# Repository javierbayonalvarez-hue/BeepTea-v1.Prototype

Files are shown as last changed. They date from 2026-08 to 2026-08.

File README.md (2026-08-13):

🌍 *[Read this in English](README.md) | [Leer en Español](README_ES.md)*

# BeepTEA

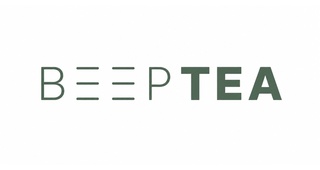
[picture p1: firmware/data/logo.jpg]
BeepTEA Logo


**BeepTEA** is a smartwatch-style smart communicator (based on the LilyGo T-Display-S3 board) specifically designed to help children and individuals with Autism Spectrum Disorder (ASD) or other cognitive needs.

Its main function is to provide visual routines using pictograms and a vibration alert system without relying on a constant internet connection, thereby improving autonomy and reducing anxiety.

---

## 🎯 Main Features
* 📵 **True Independence:** Works 100% offline after initial setup. Keeps time internally via RTC.
* 🖼️ **Visual Routines:** Displays custom pictograms to guide the user through their daily tasks (eating, washing hands, sleeping...).
* 📳 **Friendly Alerts:** The watch vibrates and emits gentle tones when it's time for a new routine, catching attention without causing distress.
* 📶 **On-Demand Connectivity:** The watch hosts its own captive portal (Direct Wi-Fi) for initial setup, and connects via **Bluetooth (BLE)** to sync routines with the mobile App.

## 📦 Project Structure

This repository contains everything needed to build and modify the entire system:

1. `/firmware`: The C++ source code for the ESP32-S3 microcontroller. Ready to be compiled with **PlatformIO**.
2. `/mobile-app`: The source code for the companion mobile application (**BeepTEA Manager**) built with **Capacitor** and vanilla HTML/JS. Allows easy pictogram uploads and routine scheduling via Bluetooth.
3. `/BOM.txt`: Bill of Materials and components used in the project.

## 🛠️ Hardware Requirements

The brain of the project is a **LilyGo T-Display-S3**, a powerful ESP32-S3 with a built-in color IPS display. We added the following to this board:

* **Vibration Motor (Haptic):** Connected to PIN 43.
* **Buzzer:** Connected to PIN 44.
* **Extra Physical Button:** (In addition to the internal buttons on PIN 0 and 14).
* **LiPo Battery:** With smart voltage monitoring (connected to PIN 4).

## 🚀 Installation Guide (Firmware)

1. Install [Visual Studio Code](https://code.visualstudio.com/) and the [PlatformIO](https://platformio.org/) extension.
2. Open the `/firmware` folder in VS Code.
3. Connect your LilyGo T-Display-S3 board via USB.
4. First, compile and upload the filesystem (LittleFS) using the **`Upload File System Image`** option in PlatformIO (this uploads the captive portal and the logo).
5. Second, compile and upload the source code using the **`Upload`** option.

## 📱 Build Guide (Mobile App)

To compile the mobile app, you will need [Node.js](https://nodejs.org/) and Android Studio.

1. Open the `/mobile-app` folder in your terminal.
2. Install dependencies: `npm install`
3. Sync the web code with the native Android project: `npx cap sync android`
4. Open it in Android Studio to build your APK: `npx cap open android`

## 🤝 Credits and Collaboration

A project created with dedication to make life easier and foster autonomy for people with ASD. Feel free to fork, improve, or propose new features by opening a *Pull Request*!

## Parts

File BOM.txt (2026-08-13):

BUSCATEA DIGITAL - BOM / LISTA DE COMPRA
Version: MVP hardware
Fecha: 2026-05-05

OBJETIVO
Dispositivo tipo busca/pager para rutinas visuales con pictogramas, vibracion, sonido, RTC y botones fisicos.

1. ELECTRONICA PRINCIPAL

[ ] 1x LILYGO T-Display-S3 ESP32-S3
    - Pantalla 1.9" ST7789, 170 x 320.
    - 16 MB Flash, 8 MB PSRAM.
    - Conector bateria JST-GH 1.25 mm 2P.
    - Mejor version sin touch para evitar distracciones.

[ ] 1x Bateria LiPo 3.7 V 1200 mAh modelo 103450
    - Preferible con circuito de proteccion integrado.
    - Conector compatible JST-GH 1.25 mm 2P o adaptador.

[ ] 1x Modulo RTC DS3231 Mini I2C
    - Alimentacion a 3.3 V.
    - Conexiones: VCC, GND, SDA, SCL.
    - Revisar si trae circuito de carga para pila LIR2032 antes de usar CR2032/CR1220.

[ ] 1x Pila para RTC
    - CR1220, CR2032 o LIR2032 segun el modulo DS3231 comprado.
    - No usar pila no recargable si el modulo intenta cargarla.

2. FEEDBACK / ALERTAS

[ ] 1x Modulo motor de vibracion tipo moneda con driver integrado
    - Pines: IN, VCC, GND.
    - Conexion recomendada:
      IN  -> GPIO 1
      VCC -> 3V3
      GND -> GND
    - Al usar este modulo NO hace falta comprar MOSFET, diodo ni resistencias para el motor.

[ ] 1x Buzzer pasivo 3 V / piezo pasivo
    - Conexion MVP:
      positivo -> GPIO 2
      negativo -> GND
    - Si el buzzer elegido consume mucho, anadir transistor/MOSFET como driver.

3. ENTRADA FISICA

[ ] 0x Pulsadores externos para el MVP de pruebas
    - De momento se usan los 2 botones integrados de la LILYGO T-Display-S3.
    - Boton integrado GPIO 0 -> OK / confirmar.
    - Boton integrado GPIO 14 -> Menu / Necesidades.
    - No hace falta comprar botones externos para probar firmware y app.

4. CARCASA Y MONTAJE

[ ] 1x Carcasa impresa en PETG
    - Formato tipo busca/pager.
    - Huecos para pantalla, USB-C, botones y sonido.
    - Espacio para bateria 103450 y cableado.

[ ] 1x Clip metalico de cinturon
    - Preferible metalico por resistencia.

[ ] 1 lote tornillos M2 / M2.5
    - Segun diseno de carcasa.

[ ] 1 lote insertos termicos M2 / M2.5
    - Recomendado si la carcasa se abre/cierra muchas veces.

[ ] 1 pieza espuma EVA fina o almohadilla adhesiva
    - Para sujetar bateria y evitar vibraciones internas.

5. HERRAMIENTAS / CONSUMIBLES

[ ] Cable USB-A a USB-C de datos
    - Para programar el LILYGO.
    - LILYGO recomienda cable USB 2.0 A-C.

[ ] Estaño fino para electronica

[ ] Flux

[ ] Cinta Kapton o aislante fino

[ ] Multimetro
    - Para comprobar continuidad, polaridad de bateria y modulo DS3231.

6. COMPONENTES QUE YA NO SON NECESARIOS SI USAS EL MODULO DE VIBRACION DE LA FOTO

[ ] MOSFET canal N para motor
[ ] Resistencia gate 100 ohm para motor
[ ] Resistencia pulldown 100k para motor
[ ] Diodo flyback para motor

Nota: mantenerlos solo si se decide usar un motor suelto sin placa driver.

7. PINOUT MVP

Motor vibracion modulo:
IN  -> GPIO 1
VCC -> 3V3
GND -> GND

Buzzer pasivo:
+ -> GPIO 2
- -> GND

Boton OK:
GPIO 0 -> boton integrado LILYGO

Boton Menu:
GPIO 14 -> boton integrado LILYGO

RTC DS3231:
VCC -> 3V3
GND -> GND
SDA -> GPIO 17
SCL -> GPIO 18

Bateria:
LiPo 3.7 V -> JST-GH 1.25 mm 2P del LILYGO

8. NOTAS DE SEGURIDAD

- No alimentar el DS3231 a 5 V.
- No usar CR2032/CR1220 si el modulo DS3231 intenta cargar la pila.
- No conectar motor suelto directamente a GPIO. El modulo de vibracion con driver si puede ir por IN.
- Todos los GND deben estar unidos.
- Proteger fisicamente la bateria dentro de la carcasa.
- Evitar piezas pequenas sueltas en un dispositivo infantil.

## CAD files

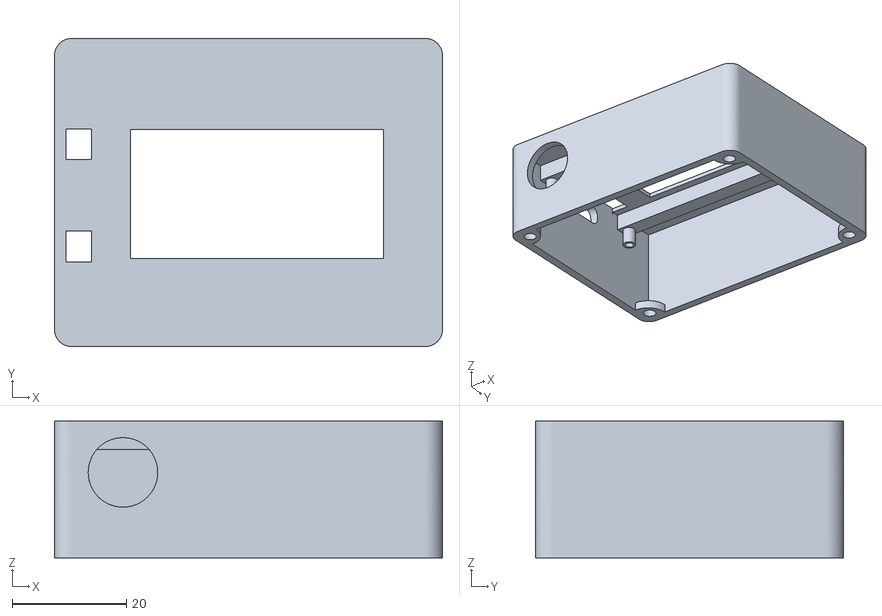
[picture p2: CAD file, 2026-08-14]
3D Models/BeepTeaTop.stl
68.0 x 54.0 x 24.0

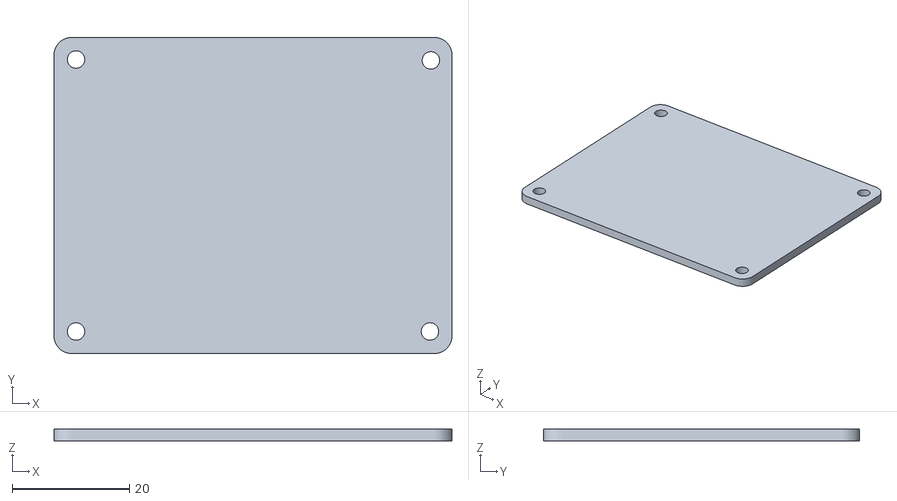
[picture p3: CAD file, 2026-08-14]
3D Models/BeepTeaBack.stl
68.0 x 54.0 x 2.00

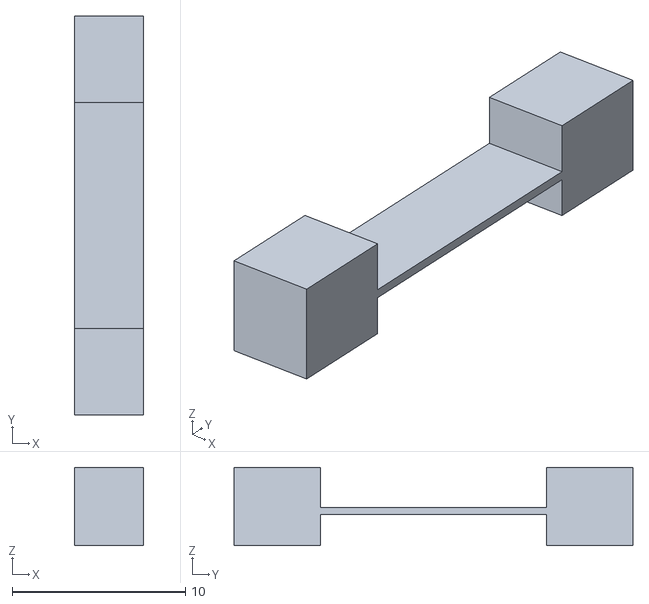
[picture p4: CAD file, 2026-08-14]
3D Models/BeepTEAButtons.stl
4.00 x 23.0 x 4.50

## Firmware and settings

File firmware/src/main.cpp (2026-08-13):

#include <Arduino.h>
#include <ArduinoJson.h>
#include <ESPAsyncWebServer.h>
#include <ESPmDNS.h>
#include <LittleFS.h>
#include <NimBLEDevice.h>
#include <Preferences.h>
#include <RTClib.h>
#include <TFT_eSPI.h>
#include <TJpg_Decoder.h>
#include <WiFi.h>
#include <Wire.h>
#include <time.h>
#include <driver/gpio.h>

#include "config.h"

struct RoutineItem {
  String id;
  String title;
  uint16_t startMin;
  uint16_t endMin;
  bool completed;
};

static TFT_eSPI tft;
static RTC_DS3231 rtc;
static AsyncWebServer server(80);
static Preferences prefs;
static NimBLECharacteristic *bleStatus = nullptr;

static bool bleConnected = false;
static RoutineItem routine[24];
static size_t routineCount = 0;
static int activeIndex = -1;
static bool rtcAvailable = false;
static bool wifiConnected = false;
static bool setupMode = false;
static bool restartPending = false;
static wl_status_t lastWifiStatus = WL_IDLE_STATUS;
static String attemptedWifiSsid = "";
static bool needsMenuOpen = false;
static bool alertRunning = false;
static uint32_t alertStartedAt = 0;
static bool deviceVibration = true;
static bool deviceSound = true;
static uint8_t routineDaysMask = 0xFF;
static uint32_t deviceAlertMs = 3000;

RTC_DATA_ATTR uint8_t brightnessLevel = 1; // 0=Bajo, 1=Medio, 2=Alto

static void applyBrightness() {
  if (brightnessLevel == 0) ledcWrite(2, 50); // 20%
  else if (brightnessLevel == 1) ledcWrite(2, 140); // 55%
  else ledcWrite(2, 255); // 100%
}

static uint32_t lastDrawAt = 0;
static uint32_t okPressedAt = 0;
static uint32_t menuPressedAt = 0;
static bool okWasDown = false;
static bool menuWasDown = false;
static uint32_t restartAt = 0;

static uint32_t lastInteractionTime = 0;
static bool screenIsAsleep = false;

static void applyNetworkMode();
static void disableNetwork();

static bool previewMode = false;
static uint32_t previewStartedAt = 0;
static int previewIndex = -1;

static String routineName = "Sin rutina";
static String childName = "BuscaTEA";
static bool infoMode = false;
static uint32_t infoStartedAt = 0;
static bool menuLongPressed = false;
static int networkMode = 0;
static int lastDrawnIndex = -2;
static bool lastDrawnNeedsMenu = false;
static uint16_t lastDrawnMinute = 9999;
static bool lastDrawnCompleted = false;
static uint8_t lastDrawnProgress = 255;
static String lastDrawnIp = "";
static int lastDrawnBattery = -1;

static bool tftJpegOutput(int16_t x, int16_t y, uint16_t w, uint16_t h, uint16_t *bitmap) {
  if (y >= SCREEN_H) return false;
  tft.pushImage(x, y, w, h, bitmap);
  return true;
}

static uint16_t parseTimeToMinutes(const String &value) {
  int sep = value.indexOf(':');
  if (sep < 0) return 0;
  int hh = value.substring(0, sep).toInt();
  int mm = value.substring(sep + 1).toInt();
  hh = constrain(hh, 0, 23);
  mm = constrain(mm, 0, 59);
  return hh * 60 + mm;
}

static String minutesToTime(uint16_t value) {
  char buffer[6];
  snprintf(buffer, sizeof(buffer), "%02u:%02u", value / 60, value % 60);
  return String(buffer);
}

static float batteryMultiplier = 2.00f;

static uint32_t readBatteryMilliVolts() {
  analogRead(PIN_BATTERY_ADC); // dummy
  uint32_t sum = 0;
  for (int i = 0; i < 16; i++) {
    sum += analogReadMilliVolts(PIN_BATTERY_ADC);
    delay(1);
  }
  uint32_t raw_mv = (sum / 16) * 2;
  // Calibración por hardware: El LED de carga marca 100% (4200mV físicos), 
  // pero el ADC lee ~3952mV debido a la tolerancia de las resistencias. 
  // Factor de corrección: 4200 / 3952 = 1.0627
  return (uint32_t)(raw_mv * 1.0627f);
}

static int batteryPercent() {
  uint32_t millivolts = readBatteryMilliVolts();
  
  struct VoltageMap {
    uint32_t mv;
    int percentage;
  };
  
  static const VoltageMap table[] = {
    {4200, 100},
    {4100, 95},
    {4000, 85},
    {3900, 75},
    {3800, 60},
    {3700, 40},
    {3600, 15},
    {3500, 5},
    {3400, 0}
  };
  
  if (millivolts >= table[0].mv) return 100;
  if (millivolts <= table[8].mv) return 0;
  
  for (int i = 0; i < 8; i++) {
    if (millivolts <= table[i].mv && millivolts >= table[i+1].mv) {
      float frac = (float)(table[i].mv - millivolts) / (table[i].mv - table[i+1].mv);
      return table[i].percentage - frac * (table[i].percentage - table[i+1].percentage);
    }
  }
  return 0;
}

static void tftSleep() {
  ledcWrite(2, 0);
  ledcDetachPin(PIN_LCD_BACKLIGHT);
  pinMode(PIN_LCD_BACKLIGHT, OUTPUT);
  digitalWrite(PIN_LCD_BACKLIGHT, LOW);
  tft.writecommand(0x10); // ST7789_SLPIN
  
  pinMode(TFT_CS, INPUT);
  pinMode(TFT_DC, INPUT);
  pinMode(TFT_RST, INPUT);
  pinMode(TFT_WR, INPUT);
  pinMode(TFT_RD, INPUT);
  pinMode(TFT_D0, INPUT);
  pinMode(TFT_D1, INPUT);
  pinMode(TFT_D2, INPUT);
  pinMode(TFT_D3, INPUT);
  pinMode(TFT_D4, INPUT);
  pinMode(TFT_D5, INPUT);
  pinMode(TFT_D6, INPUT);
  pinMode(TFT_D7, INPUT);
  
  digitalWrite(PIN_POWER_ON, LOW);
  gpio_hold_en((gpio_num_t)PIN_POWER_ON); // Bloqueo hermético del pin en sleep
}

class TFT_eSPI_Hack : public TFT_eSPI {
public:
  void forceBooted() { _booted = true; }
};

static void tftWake() {
  gpio_hold_dis((gpio_num_t)PIN_POWER_ON);
  digitalWrite(PIN_POWER_ON, HIGH);
  delay(120); 
  
  ((TFT_eSPI_Hack*)&tft)->forceBooted();
  tft.init();
  tft.writecommand(0x11); // SLPOUT
  delay(120);
  
  ledcSetup(2, 10000, 8);
  ledcAttachPin(PIN_LCD_BACKLIGHT, 2);
  applyBrightness();
}

static String activeIp() {
  if (wifiConnected) return WiFi.localIP().toString();
  if (setupMode) return WiFi.softAPIP().toString();
  return "0.0.0.0";
}

static String wifiModeName() {
  if (wifiConnected) return "station";
  if (setupMode) return "setup";
  return "offline";
}

static String wifiStatusName(wl_status_t status) {
  switch (status) {
    case WL_IDLE_STATUS: return "IDLE";
    case WL_NO_SSID_AVAIL: return "NO_SSID";
    case WL_SCAN_COMPLETED: return "SCAN_DONE";
    case WL_CONNECTED: return "CONNECTED";
    case WL_CONNECT_FAILED: return "CONNECT_FAILED";
    case WL_CONNECTION_LOST: return "CONNECTION_LOST";
    case WL_DISCONNECTED: return "DISCONNECTED";
    default: return String(static_cast<int>(status));
  }
}

static void updateBleStatus();
static void drawScreen(bool force = false);

static uint16_t currentMinuteOfDay() {
  if (rtcAvailable) {
    DateTime now = rtc.now();
    return now.hour() * 60 + now.minute();
  }

  uint32_t seconds = millis() / 1000;
  return (seconds / 60) % 1440;
}

static uint16_t currentToneFreq = 0;
static void safeTone(uint16_t freq) {
  if (currentToneFreq != freq) {
    currentToneFreq = freq;
    ledcWriteTone(0, freq);
  }
}

static void buzz(uint16_t freq, uint16_t durationMs) {
  safeTone(freq);
  delay(durationMs);
  safeTone(0);
}

static void startTransitionAlert() {
  if (screenIsAsleep) {
    screenIsAsleep = false;
    tftWake();
    tft.setRotation(1);
    drawScreen(true);
  }

  alertRunning = true;
  alertStartedAt = millis();
  lastInteractionTime = millis();
  if (deviceVibration) {
    digitalWrite(PIN_VIBRATION, HIGH);
  }
  if (deviceSound) {
  }
}

static void updateAlert() {
  if (!alertRunning) return;
  uint32_t elapsed = millis() - alertStartedAt;
  
    if (elapsed >= deviceAlertMs) {
    digitalWrite(PIN_VIBRATION, LOW);
    if (deviceSound) safeTone(0);
    alertRunning = false;
    return;
  }
  
  if (deviceSound) {
    uint32_t t = elapsed % 1600;
    if (t < 600) {
      uint32_t cycle = t % 150;
      if (cycle < 100) safeTone(4000);
      else safeTone(0);
    } else {
      safeTone(0);
    }
  }
}

static bool loadRoutine() {
  routineCount = 0;
  routineName = "Sin rutina";
  File file = LittleFS.open(ROUTINE_PATH, "r");
  if (!file) return false;

  JsonDocument doc;
  DeserializationError err = deserializeJson(doc, file);
  file.close();
  if (err) return false;

  routineName = doc["name"] | "Sin rutina";
  childName = doc["child"] | "BuscaTEA";
  deviceVibration = doc["vibration"] | true;
  deviceSound = doc["sound"] | true;
  routineDaysMask = 0;
  JsonArray dArr = doc["days"].as<JsonArray>();
  if (dArr.isNull() || dArr.size() == 0) {
    routineDaysMask = 0xFF;
  } else {
    for (JsonVariant v : dArr) {
      routineDaysMask |= (1 << v.as<int>());
    }
  }
  int durationSec = doc["alertDuration"] | 3;
  deviceAlertMs = durationSec * 1000;

  JsonArray items = doc["items"].as<JsonArray>();
  for (JsonObject item : items) {
    if (routineCount >= 24) break;
    routine[routineCount].id = item["id"] | "";
    routine[routineCount].title = item["title"] | routine[routineCount].id;
    routine[routineCount].startMin = parseTimeToMinutes(item["start"] | "00:00");
    routine[routineCount].endMin = parseTimeToMinutes(item["end"] | "00:00");
    routine[routineCount].completed = false;
    routineCount++;
  }
  return routineCount > 0;
}

static int findActiveRoutineIndex(uint16_t minute) {
  if (rtcAvailable) {
    DateTime now = rtc.now();
    int dayW = now.dayOfTheWeek();
    int mappedDay = (dayW == 0) ? 7 : dayW;
    if (!(routineDaysMask & (1 << mappedDay))) {
      return -1;
    }
  }
  for (size_t i = 0; i < routineCount; i++) {

    if (routine[i].startMin <= routine[i].endMin) {
      if (minute >= routine[i].startMin && minute < routine[i].endMin) return i;
    } else {
      if (minute >= routine[i].startMin || minute < routine[i].endMin) return i;
    }
  }
  return -1;
}

static uint8_t progressFor(const RoutineItem &item, uint16_t minute) {
  int start = item.startMin;
  int end = item.endMin;
  int now = minute;

  if (end <= start) end += 1440;
  if (now < start) now += 1440;

  int total = max(1, end - start);
  int elapsed = constrain(now - start, 0, total);
  return (elapsed * 100) / total;
}

static void drawBatteryIcon(int x, int y, int w, int h, int percent, bool charging) {
  uint16_t color = tft.color565(16, 185, 129);
  if (charging) {
    color = TFT_YELLOW;
  } else if (percent < 20) {
    color = tft.color565(239, 68, 68);
  } else if (percent < 50) {
    color = tft.color565(249, 115, 22);
  }
  
  tft.drawRect(x, y, w - 2, h, color);
  tft.fillRect(x + w - 2, y + 2, 2, h - 4, color);
  
  if (charging) {
    tft.fillRect(x + 2, y + 2, w - 6, h - 4, color);
    tft.drawLine(x + w/2 - 2, y + 2, x + w/2, y + h/2, TFT_BLACK);
    tft.drawLine(x + w/2, y + h/2, x + w/2 - 2, y + h/2, TFT_BLACK);
    tft.drawLine(x + w/2 - 2, y + h/2, x + w/2 + 2, y + h - 2, TFT_BLACK);
  } else {
    int fillW = ((w - 4) * percent) / 100;
    if (fillW > 0) {
      tft.fillRect(x + 2, y + 2, fillW, h - 4, color);
    }
  }
}

static void drawWifiIcon(int x, int y, int rssi, bool apMode, bool connected) {
  if (!connected) {
    if (apMode) {
      tft.setTextDatum(ML_DATUM);
      tft.setTextColor(tft.color565(249, 115, 22), tft.color565(15, 23, 42));
      tft.drawString("AP", x, y + 4, 1);
    } else {
      uint16_t gray = tft.color565(80, 80, 90);
      tft.fillRect(x, y + 6, 2, 2, gray);
      tft.fillRect(x + 4, y + 4, 2, 4, gray);
      tft.fillRect(x + 8, y + 2, 2, 6, gray);
      tft.fillRect(x + 12, y, 2, 8, gray);
      tft.drawLine(x - 2, y, x + 14, y + 8, tft.color565(239, 68, 68));
    }
  } else {
    int bars = 1;
    if (rssi >= -55) bars = 4;
    else if (rssi >= -70) bars = 3;
    else if (rssi >= -85) bars = 2;
    
    uint16_t barColor = tft.color565(16, 185, 129);
    uint16_t inactiveColor = tft.color565(50, 50, 60);
    
    tft.fillRect(x, y + 6, 2, 2, (bars >= 1) ? barColor : inactiveColor);
    tft.fillRect(x + 4, y + 4, 2, 4, (bars >= 2) ? barColor : inactiveColor);
    tft.fillRect(x + 8, y + 2, 2, 6, (bars >= 3) ? barColor : inactiveColor);
    tft.fillRect(x + 12, y, 2, 8, (bars >= 4) ? barColor : inactiveColor);
  }
}

static void drawBleIcon(int x, int y, bool connected) {
  uint16_t color = connected ? tft.color565(59, 130, 246) : tft.color565(80, 80, 90);
  tft.drawLine(x + 3, y, x + 3, y + 8, color);
  tft.drawLine(x + 3, y, x + 6, y + 2, color);
  tft.drawLine(x + 6, y + 2, x + 3, y + 4, color);
  tft.drawLine(x + 3, y + 4, x + 6, y + 6, color);
  tft.drawLine(x + 6, y + 6, x + 3, y + 8, color);
  tft.drawLine(x + 3, y + 2, x, y, color);
  tft.drawLine(x + 3, y + 6, x, y + 8, color);
}

static void drawSoundIcon(int x, int y, bool enabled) {
  uint16_t color = enabled ? tft.color565(186, 195, 210) : tft.color565(80, 80, 90);
  tft.fillRect(x, y + 2, 3, 4, color);
  tft.drawLine(x + 3, y + 2, x + 6, y, color);
  tft.drawLine(x + 3, y + 5, x + 6, y + 7, color);
  tft.fillRect(x + 6, y, 1, 8, color);
  if (enabled) {
    tft.drawPixel(x + 8, y + 2, color);
    tft.drawPixel(x + 9, y + 3, color);
    tft.drawPixel(x + 9, y + 4, color);
    tft.drawPixel(x + 8, y + 5, color);
  }
}

static void drawVibrationIcon(int x, int y, bool enabled) {
  uint16_t color = enabled ? tft.color565(186, 195, 210) : tft.color565(80, 80, 90);
  tft.drawRect(x + 2, y + 1, 6, 8, color);
  if (enabled) {
    tft.drawPixel(x, y + 2, color);
    tft.drawPixel(x + 1, y + 3, color);
    tft.drawPixel(x + 1, y + 5, color);
    tft.drawPixel(x, y + 6, color);
    tft.drawPixel(x + 9, y + 2, color);
    tft.drawPixel(x + 8, y + 3, color);
    tft.drawPixel(x + 8, y + 5, color);
    tft.drawPixel(x + 9, y + 6, color);
  }
}

static void drawRoundRectGradientH(int x, int y, int w, int h, int r, uint16_t colorStart, uint16_t colorEnd) {
  uint8_t rS = (colorStart >> 11) & 0x1F;
  uint8_t gS = (colorStart >> 5) & 0x3F;
  uint8_t bS = colorStart & 0x1F;
  
  uint8_t rE = (colorEnd >> 11) & 0x1F;
  uint8_t gE = (colorEnd >> 5) & 0x3F;
  uint8_t bE = colorEnd & 0x1F;
  
  for (int i = 0; i < w; i++) {
    float t = (float)i / (w - 1);
    uint8_t rC = rS + t * (rE - rS);
    uint8_t gC = gS + t * (gE - gS);
    uint8_t bC = bS + t * (bE - bS);
    uint16_t color = (rC << 11) | (gC << 5) | bC;
    
    int dy = 0;
    if (i < r) {
      int dx = r - i;
      dy = sqrt(r * r - dx * dx);
      tft.drawFastVLine(x + i, y + r - dy, 2 * dy + (h - 2 * r), color);
    } else if (i >= w - r) {
      int dx = i - (w - r);
      dy = sqrt(r * r - dx * dx);
      tft.drawFastVLine(x + i, y + r - dy, 2 * dy + (h - 2 * r), color);
    } else {
      tft.drawFastVLine(x + i, y, h, color);
    }
  }
}
static bool isCharging() {
  static uint32_t lastCheckMillis = 0;
  static uint32_t lastVolts = 0;
  static bool chargingState = false;
  
  uint32_t currentVolts = readBatteryMilliVolts();
  uint32_t now = millis();
  
  // Inicialización en el primer arranque
  if (lastVolts == 0) {
    lastVolts = currentVolts;
    lastCheckMillis = now;
    // Si al arrancar el voltaje es inusualmente alto (por encima del 100% natural), asumimos que está enchufado
    if (currentVolts > 4250) chargingState = true; 
    return chargingState;
  }
  
  // Revisamos la tendencia cada 2 segundos
  if (now - lastCheckMillis > 2000) {
    int32_t delta = (int32_t)currentVolts - (int32_t)lastVolts;
    
    // Idea 1: Salto brusco hacia arriba (>50mV en 2 seg) = Acaban de enchufar el cable
    if (delta > 50) {
      chargingState = true;
    } 
    // Bajón brusco rápido (>-50mV) = Acaban de quitar el cable
    else if (delta < -50) {
      chargingState = false;
    }
    
    // Seguridad: Si el voltaje es mecánicamente superior al tope natural de la batería, está enchufado
    if (currentVolts > 4250) {
      chargingState = true;
    }
    
    // Idea 2: Si hay conexión de datos USB por puerto serie con un PC, sabemos seguro que está enchufado
    if (Serial) {
      chargingState = true;
    }
    
    lastVolts = currentVolts;
    lastCheckMillis = now;
  }
  
  return chargingState;
}

static void drawHeader(uint16_t minute) {
  tft.fillRect(0, 0, SCREEN_W, 22, tft.color565(15, 23, 42));
  tft.drawFastHLine(0, 22, SCREEN_W, tft.color565(51, 65, 85));

  tft.setTextDatum(ML_DATUM);
  tft.setTextColor(TFT_WHITE, tft.color565(15, 23, 42));
  tft.drawString(minutesToTime(minute), 10, 11, 2);

  tft.setTextDatum(MC_DATUM);
  tft.setTextColor(tft.color565(148, 163, 184), tft.color565(15, 23, 42));
  tft.drawString(childName, 95, 11, 2);

  int bat = batteryPercent();
  bool charging = isCharging();
  
  tft.setTextDatum(MR_DATUM);
  if (charging) {
    tft.setTextColor(TFT_YELLOW, tft.color565(15, 23, 42));
    tft.drawString("CHG", 292, 11, 2);
  } else {
    tft.setTextColor(TFT_WHITE, tft.color565(15, 23, 42));
    tft.drawString(String(bat), 292, 11, 2);
  }

  drawBatteryIcon(296, 4, 20, 10, bat, charging);
  int rssi = wifiConnected ? WiFi.RSSI() : -100;
  drawWifiIcon(250, 7, rssi, setupMode, wifiConnected);
  drawBleIcon(230, 7, bleConnected);
  drawVibrationIcon(210, 7, deviceVibration);
  drawSoundIcon(190, 7, deviceSound);
}

static void drawBorderProgress(int x, int y, int w, int h, int thickness, uint8_t progress, uint16_t activeColor, uint16_t inactiveColor) {
  for (int t = 0; t < thickness; t++) {
    tft.drawRect(x - t, y - t, w + 2 * t, h + 2 * t, inactiveColor);
  }

  int topProgress = constrain(progress, 0, 25);
  for (int t = 0; t < thickness; t++) {
    int topW = (topProgress * (w + 2 * t)) / 25;
    tft.drawFastHLine(x - t, y - t, topW, activeColor);
  }

  if (progress > 25) {
    int rightProgress = constrain(progress - 25, 0, 25);
    for (int t = 0; t < thickness; t++) {
      int rightH = (rightProgress * (h + 2 * t)) / 25;
      tft.drawFastVLine(x + w - 1 + t, y - t, rightH, activeColor);
    }
  }

  if (progress > 50) {
    int bottomProgress = constrain(progress - 50, 0, 25);
    for (int t = 0; t < thickness; t++) {
      int bottomW = (bottomProgress * (w + 2 * t)) / 25;
      tft.drawFastHLine(x + w - 1 + t - bottomW, y + h - 1 + t, bottomW, activeColor);
    }
  }

  if (progress > 75) {
    int leftProgress = constrain(progress - 75, 0, 25);
    for (int t = 0; t < thickness; t++) {
      int leftH = (leftProgress * (h + 2 * t)) / 25;
      tft.drawFastVLine(x - t, y + h - 1 + t - leftH, leftH, activeColor);
    }
  }
}

static int findNextRoutineIndex(uint16_t minute) {
  if (routineCount == 0) return -1;
  if (rtcAvailable) {
    DateTime now = rtc.now();
    int dayW = now.dayOfTheWeek();
    int mappedDay = (dayW == 0) ? 7 : dayW;
    if (!(routineDaysMask & (1 << mappedDay))) return -1;
  }
  if (activeIndex >= 0 && (size_t)(activeIndex + 1) < routineCount) {
    return activeIndex + 1;
  }
  for (size_t i = 0; i < routineCount; i++) {
    if (routine[i].startMin > minute) {
      return i;
    }
  }
  return 0;
}

static bool drawPictogramImage(const RoutineItem &item, int picX, int picY, int picW, int picH) {
  String jpgPath = "/pictos/" + item.id + ".jpg";
  String jpegPath = "/pictos/" + item.id + ".jpeg";
  String path = LittleFS.exists(jpgPath) ? jpgPath : jpegPath;
  if (!LittleFS.exists(path)) return false;

  tft.fillRect(picX, picY, picW, picH, TFT_WHITE);

  uint16_t jpgW = 0;
  uint16_t jpgH = 0;
  TJpgDec.getFsJpgSize(&jpgW, &jpgH, path, LittleFS);
  uint8_t scale = 1;
  while ((jpgW / scale > (picW - 6) || jpgH / scale > (picH - 6)) && scale < 8) {
    scale *= 2;
  }
  TJpgDec.setJpgScale(scale);

  int16_t drawW = jpgW / scale;
  int16_t drawH = jpgH / scale;
  int16_t x = picX + max(0, (picW - drawW) / 2);
  int16_t y = picY + max(0, (picH - drawH) / 2);
  TJpgDec.drawFsJpg(x, y, path, LittleFS);
  return true;
}

static void drawPictogramPlaceholder(const RoutineItem &item, int picX, int picY, int picW, int picH) {
  tft.fillRect(picX, picY, picW, picH, TFT_WHITE);
  tft.setTextDatum(MC_DATUM);
  tft.setTextColor(TFT_BLACK, TFT_WHITE);
  tft.drawString(item.id.substring(0, 10), picX + picW / 2, picY + picH / 2, 2);
}
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
void loop() {
  handleButtons();
  updateAlert();
  
  if (!screenIsAsleep) {
    drawScreen();
    
    if (!previewMode && !infoMode) {
      uint32_t timeoutMs = (activeIndex >= 0) ? 180000 : 60000;
      if (millis() - lastInteractionTime > timeoutMs) {
        screenIsAsleep = true;
        tftSleep();
      }
    }
  } else {
    Serial.flush();
    Serial.end();
    
    gpio_wakeup_enable((gpio_num_t)PIN_BUTTON_OK, GPIO_INTR_LOW_LEVEL);
    gpio_wakeup_enable((gpio_num_t)PIN_BUTTON_MENU, GPIO_INTR_LOW_LEVEL);
    esp_sleep_enable_gpio_wakeup();
    
    esp_sleep_enable_timer_wakeup(60000000ULL);
    
    esp_err_t err = esp_light_sleep_start();
    if (err != ESP_OK) {
      Serial.begin(115200);
      Serial.printf("Light sleep failed! err: %d\n", err);
      delay(1000);
    } else {
      Serial.begin(115200);
    }
    
    esp_sleep_wakeup_cause_t cause = esp_sleep_get_wakeup_cause();
    if (cause == ESP_SLEEP_WAKEUP_TIMER) {
      uint16_t minute = currentMinuteOfDay();
      
      static uint16_t lastMinuteSleep = 9999;
      if (lastMinuteSleep != 9999 && minute < lastMinuteSleep) {
        for (size_t i = 0; i < routineCount; i++) routine[i].completed = false;
      }
      lastMinuteSleep = minute;

      int nextActive = findActiveRoutineIndex(minute);
      if (nextActive != activeIndex) {
        screenIsAsleep = false;
        tftWake();
        tft.setRotation(1);
        lastInteractionTime = millis();
        drawScreen(true);
      }
    } else if (cause == ESP_SLEEP_WAKEUP_GPIO || cause == ESP_SLEEP_WAKEUP_EXT1) {
      screenIsAsleep = false;
      tftWake();
      tft.setRotation(1);
      okWasDown = true;
      menuWasDown = true;
      lastInteractionTime = millis();
      drawScreen(true);
    }
  }
  if (restartPending && millis() >= restartAt) {
    ESP.restart();
  }
  static uint32_t lastBleUpdate = 0;
  if (millis() - lastBleUpdate > 5000) {
    lastBleUpdate = millis();
    updateBleStatus();
  }
}

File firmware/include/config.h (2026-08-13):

#pragma once

#include <Arduino.h>

#if defined(ARDUINO_SEEED_XIAO_ESP32S3)
static constexpr uint16_t SCREEN_W = 320;
static constexpr uint16_t SCREEN_H = 240;

static constexpr uint8_t PIN_VIBRATION = 43;      // D6
static constexpr uint8_t PIN_BUZZER = 44;         // D7
static constexpr uint8_t PIN_BUTTON_OK = 1;       // D0
static constexpr uint8_t PIN_BUTTON_MENU = 2;     // D1
static constexpr uint8_t PIN_POWER_ON = 15;       // Unused GPIO on XIAO (acting as dummy)
static constexpr uint8_t PIN_BATTERY_ADC = 4;     // D3 / A3
static constexpr uint8_t PIN_LCD_BACKLIGHT = 8;   // D9

static constexpr uint8_t PIN_I2C_SDA = 5;         // D4
static constexpr uint8_t PIN_I2C_SCL = 6;         // D5
#else
static constexpr uint16_t SCREEN_W = 320;
static constexpr uint16_t SCREEN_H = 170;

static constexpr uint8_t PIN_VIBRATION = 1;
static constexpr uint8_t PIN_BUZZER = 2;
static constexpr uint8_t PIN_BUTTON_OK = 0;
static constexpr uint8_t PIN_BUTTON_MENU = 14;
static constexpr uint8_t PIN_POWER_ON = 15;
static constexpr uint8_t PIN_BATTERY_ADC = 4;
static constexpr uint8_t PIN_LCD_BACKLIGHT = 38;

static constexpr uint8_t PIN_I2C_SDA = 17;
static constexpr uint8_t PIN_I2C_SCL = 18;
#endif


static constexpr uint32_t LONG_PRESS_MS = 900;
static constexpr uint32_t DISPLAY_REFRESH_MS = 1000;
static constexpr uint32_t ALERT_PATTERN_MS = 1400;

static constexpr const char *ROUTINE_PATH = "/rutina.json";
static constexpr const char *DEVICE_NAME = "buscatea-demo";
static constexpr const char *AP_SSID = "BeepTea Setup";
static constexpr const char *AP_PASSWORD = "btea1234";
static constexpr uint32_t WIFI_CONNECT_TIMEOUT_MS = 15000;

// Credenciales opcionales para pruebas. Si no hay Wi-Fi guardada por BLE/API,
// el firmware intentara conectarse a esta red antes de abrir BuscaTea-Setup.
static constexpr const char *DEFAULT_WIFI_SSID = "";
static constexpr const char *DEFAULT_WIFI_PASSWORD = "";
static constexpr bool FORCE_DEFAULT_WIFI = false;

static constexpr const char *BLE_SERVICE_UUID = "7d2f6a40-8f4f-4a9f-9f25-2f5a6f0b1000";
static constexpr const char *BLE_STATUS_UUID = "7d2f6a40-8f4f-4a9f-9f25-2f5a6f0b1001";
static constexpr const char *BLE_WIFI_UUID = "7d2f6a40-8f4f-4a9f-9f25-2f5a6f0b1002";
